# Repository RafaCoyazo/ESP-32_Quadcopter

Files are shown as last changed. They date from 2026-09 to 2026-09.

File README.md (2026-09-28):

# ESP-32_Quadcopter

Purpose:
This repository documents a summer project dedicated to designing and building a custom quadcopter from scratch. At the core of the drone is a custom-designed PCB featuring an ESP32 microcontroller and an onboard accelerometer. While the final build has not yet achieved stable flight, the project served as an intensive, hands-on exploration of embedded C++, custom PCB routing, and writing raw PID control loops for hardware stabilization.

## Current Status & Known Issues

The physical build and custom PCB are complete, and the ESP32 successfully interfaces with the MPU6050 IMU and all four ESCs. However, the drone currently experiences a thrust imbalance where the rear motors do not reach the same RPM as the front motors, preventing a stable takeoff. 

**Troubleshooting to date:**

* Swapped the rear ESCs to rule out faulty hardware; the RPM deficit persisted.
* The isolated problem likely lies within the firmware's motor mixing logic, a bug in the PWM signal generation routed to the rear pins, or an uncompensated center of gravity on the 3D-printed frame.

## Hardware & Design

## Hardware Specifications

| Component | Description |
| :--- | :--- |
| **Microcontroller Evolution** | **V1 & V2:** Arduino (View [Version 1 Details](./Version_1) and [Version 2 Details](./Version_2))
|**Version 3**| **V3 Details of the Hardware:** [Version 3 Details](./Version_3)
  
* **Flight Controller:**
  * **Version 1:** Initial proof-of-concept testing was done using an Arduino and jumper wires.
  *  **Version 2:** Upgraded to a custom double-layer PCB (View the [KiCad Project Files](./Version_3/KiCadV3)) to show proof of concept with Arduino Nano
  * **Version 3:** Redigned custom double-layer PCB (View the [KiCad Project Files](./Version_3/KiCadV3)) to integrate the ESP32 and peripherals, wiring and reduce electrical noise.
 * **Schematic Design for V3**
*(Below: The wiring schematic integrating the ESP32 microcontroller, MPU6050 IMU, and peripheral modules.)*
  
  

**Frame Design & Manufacturing** 
*(Below: The original CAD model showcasing the structural assembly, followed by the final 3D-printed physical frame.)*


rplace with image]

## Software 

* **Language & Codebase Evolution:**
  * **V1 & V2:** Arduino / C++ (View [Version 1 Code](./Version_1) and [Version 2 Code](./Version_2)).
  * **V3:** Embedded C++ (View [Version 3 Code](./Version_3/CodeV3)).
* **Flight Logic:** Custom-written PID control loops to process IMU data and calculate real-time motor compensation.
* **Communication:** I2C protocol for reading sensor telemetry and PWM signal generation for the ESCs.

## Project Media
*(Note to self: Upload a photo of the completed drone and video)*

## Takeoff Dynamics & Motor Imbalance Diagnostics

During takeoff testing, the aircraft experienced a severe pitch imbalance where the rear motors visibly and physically generated significantly lower RPM and thrust compared to the front motors, preventing vertical liftoff.

### Diagnosed Causes & Experimental Troubleshooting:

1. **Power Supply & Input Voltage Verification:**
   * **Action:** Measured the primary voltage supply lines under load to check for power starvation or voltage drops to the rear power distribution traces.
   * **Result:** Confirmed that the power supply unit consistently delivers 12V across all board rails and ESC power feeds. Power delivery was ruled out as the root cause.

2. **ESC Timing, Calibration & Hardware Swaps:**
   * **Hypothesis:** Because four individual ESCs are used rather than an integrated 4-in-1 board, timing drift or throttle calibration offsets could cause rotational speed discrepancies between channels.
   * **Action:** Replaced the rear Electronic Speed Controllers with brand-new units to test for hardware degradation and calibration drift.
   * **Result:** Installing new ESCs slightly increased the RPM of one rear motor, but the total thrust was still insufficient to equalize the outputs. This confirms that while minor ESC variances exist, the main bottleneck is not faulty ESC hardware.

3. **Firmware Pitch Control Loops & Sensor Isolation:**
   * **Action:** To test if the MPU6050 IMU feedback loop was falsely commanding lower duty cycles to the rear channels, firmware was modified to temporarily isolate and disable active pitch compensation.
   * **Result:** Testing is currently ongoing to evaluate raw PWM output signal scaling, timer channel allocations on the ESP32 pins, and pitch PID loop behavior.

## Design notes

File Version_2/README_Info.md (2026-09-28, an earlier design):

# Version 2: Failure Analysis & Root Cause Analysis

## Overview
Version 2 was designed to resolve the wireless link drops and signal instability observed in the initial Version 1 breadboard setup. The objective was to eliminate point-to-point jumper wire noise by routing a custom double-layer PCB in KiCad and upgrading the RF transceivers. However, despite custom PCB fabrication and hardware iteration, persistent communication failures prevented stable flight operations, ultimately deciding to pivot to the ESP32 in Version 3.

## Initial Problem Statement and Hypotheses
During testing on Version 1, the flight controller failed to establish a stable wireless connection between the Arduino Nano and the initial 2.4 GHz NRF24L01+ radio module. 

Primary Hypothesis: High jumper wire impedance, breadboard contact resistance, and causing signal degradation into the SPI bus lines, preventing proper module initialization.
## Experimental Iterations and Diagnostics
To test this hypothesis and systematically isolate the failure, so I made a custom PCB and tested across two transceiver configurations:

1. Custom Double-Layer PCB Fabrication (NRF24L01+ Testing)
Designed and fabricated a custom double-layer flight controller PCB in KiCad to eliminate all long jumper wires and point-to-point breadboard connections. The board integrated socket headers for the LAFVIN Arduino Nano V3.0, dedicated ground copper pours, and direct trace routing to an NRF24L01+ header.

Result: Eliminating the long wires via the custom PCB did not resolve the connection failure, proving that signal path length and breadboard noise were not the primary root cause.

3. Transceiver Module Swap (CC1101 on original PCB Layout)
Using the same custom PCB design, the NRF24L01+ module was replaced with a CC1101 multi-band wireless module equipped with an external SMA antenna to test if switching radio architecture and frequency bands would establish a connection.
Result: The CC1101 module on the custom PCB also failed to achieve reliable communication, meaning there was another cause for this problem.

## Root Cause Breakdown
After these hardware iterations across breadboards and custom PCBs, three core problems were found:

A. Microcontroller Processing and SPI Overhead
The ATmega328P (16 MHz single-core) microcontroller on the Arduino Nano lacked the processing bandwidth to reliably manage low-level SPI transceiver state machines while simultaneously executing high-frequency MPU6050 IMU reads, PID calculations, and ESC PWM updates.

B. SPI Bus Sensitivity and Driver Instability
External SPI radio modules require heavy software polling and strict timing buffers. Power ripple from motor draws or minor bus timing delays caused the SPI driver to hang, freezing communication entirely regardless of whether wires or copper PCB traces were used.

C. Airframe Mechanical Flexibility
The initial 3D-printed airframe lacked structural rigidity, allowing motor vibrations to transfer directly to the flight controller board and IMU sensor, adding mechanical noise into the system.

## Key Lessons and to improve on to Version 3
Rather than continuing to debug an architectural combination (Arduino Nano + External SPI Radio) that repeatedly failed on both breadboards and custom PCBs, the project was restructured for Version 3:

Microcontroller Upgrade: Migrated from the ATmega328P Ardunio to the ESP32 DevKit , providing better clock speed and memory overhead and a built in comunication module.

(ESP-NOW): Scrapped external SPI transceivers entirely in favor of the ESP32's native ESP-NOW protocol. ESP-NOW communicates directly on the Wi-Fi MAC layer, completely removing SPI hardware buses, radio sub-boards, and external driver overhead.

Airframe Redesign: Redesigned the 3D-printed frame in CAD with optimized infill geometry and wall thickness to isolate motor vibrations from the flight controller board.

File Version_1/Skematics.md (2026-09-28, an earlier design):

# Version 1: Schematics & Build Photos


Below is the wiring schematic and early prototype photos for the Version 1 drone build.

## Schematic Diagram


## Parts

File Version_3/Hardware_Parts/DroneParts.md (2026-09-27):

# Drone Hardware: Bill of Materials (BOM)

Below is the complete list of components required for the Version 3 quadcopter build and the custom ground controller, including both off-the-shelf electronics and custom-manufactured parts.

## Custom Manufactured Parts
| Component | Specification / Origin | Quantity | Notes |
| :--- | :--- | :--- | :--- |
| **Flight Controller Board** | Custom Double-Layer PCB | 1 | Routed in KiCad. (View [KiCad Project Files](../KiCadV3)) |
| **Quadcopter Frame** | Custom FDM 3D Print | 1 | Modeled in SolidWorks and Fusion 360. Includes arms, top plate, and undercarriage. (View [CAD Files](../CadFilesV3)) |
| **Controller Enclosure** | Custom FDM 3D Print | 1 | Houses the ESP32 transmitter board, dual joysticks, and wiring. |

## Off-The-Shelf Electronics
| Component | Specification / Model | Quantity | Notes |
| :--- | :--- | :--- | :--- |
| **Microcontroller** | ESP-WROOM-32 ESP32 Development Board | 2 | 2.4GHz Dual-Core WiFi/Bluetooth. (1 for the flight controller, 1 for the remote controller) |
| **Controller Joysticks** | KY-023 Dual-axis XY Joystick Module | 2 | PS2-style analog joysticks for reading pilot input (Throttle/Yaw, Pitch/Roll) |
| **Motors** | A2212 1000KV Brushless Outrunner | 4 | Configured for an 880g thrust profile on a 3S battery |
| **Propellers** | 1045 CW & CCW Props | 4 | 2 Clockwise, 2 Counter-Clockwise |
| **ESCs** | 40A OPTO 2-6S Brushless ESC | 4 | Handles motor current distribution without an integrated BEC |
| **IMU / Sensor** | GY-521 MPU6050 | 1 | 6-Axis Accelerometer and Gyroscope communicating via I2C |
| **Power Distribution** | Acxico 3-4S PDB with XT60 | 1 | Steps down battery voltage to provide clean 5V/12V logic power |
| **Battery** | 11.1V 3S 2200mAh 50C LiPo | 1 | High-discharge power source for flight |
| **Connectors** | XT60 Pigtails (14AWG Wire) | As needed | Soldered for high-current battery mating and power routing |

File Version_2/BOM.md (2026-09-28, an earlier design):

# Version 2: Hardware Bill of Materials (BOM)

Below is the list of components for the Version 2 build. This iteration marks the transition away from off-the-shelf prototyping boards to the first custom-designed PCB and the initial attempt at a 3D-printed airframe.

## Custom Manufactured Parts
| Component | Specification / Origin | Quantity | Notes |
| :--- | :--- | :--- | :--- |
| **Flight Controller Board** | Custom Double-Layer PCB | 1 | Early revision routed in KiCad to replace the point-to-point soldered perfboards. |
| **Quadcopter Frame** | Custom FDM 3D Print | 1 | The initial, highly experimental airframe iteration. (Replaced in Version 3 due to structural/flight issues). |

## Off-The-Shelf Electronics
| Component | Specification / Model | Quantity | Notes |
| :--- | :--- | :--- | :--- |
| **Microcontroller** | LAFVIN Nano V3.0 (ATmega328P) | 2 | Retained from Version 1 for both flight and ground control logic. |
| **Wireless Module** | CC1101 Multi-Band Wireless Module | 2 | Swapped in to replace the NRF24L01+. Includes an SMA antenna for improved range and stability. |
| **Motors** | A2212 1000KV Brushless Motors 13T | 4 | High-torque outrunner motors equipped with pre-soldered 3.5mm banana plugs. |
| **ESCs** | 30A OPTO 2-6S Brushless ESC | 4 | Electronic speed controllers for power distribution to the motors. |

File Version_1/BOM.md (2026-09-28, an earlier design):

# Version 1: Hardware Bill of Materials (BOM)

Below is the list of early components used in Version 1 of the quadcopter and ground station, prior to the migration to custom PCBs and ESP32 microcontrollers.

| Component | Specification / Model | Quantity | Notes |
| :--- | :--- | :--- | :--- |
| **Microcontroller** | LAFVIN Nano V3.0 (ATmega328P) | 2 | Driven by the CH340 chip. Used for the original flight controller and remote logic.[cite: 12] |
| **Wireless Module** | HiLetgo NRF24L01+ 2.4G Transceiver | 2 | Handled the RF communication link between the remote and the aircraft.[cite: 13] |
| **Prototyping Board** | ElectroCookie Mini PCB Prototype Board | As needed | Used to solder the Nano, NRF24L01+, and wiring point-to-point before custom PCBs were designed.[cite: 16] |
| **Motors** | A2212 1000KV Brushless Motors 13T | 4 | High-torque outrunner motors equipped with pre-soldered 3.5mm banana plugs.[cite: 15] |
| **ESCs** | 30A OPTO 2-6S Brushless ESC | 4 | Electronic speed controllers for power distribution to the motors.[cite: 14] |

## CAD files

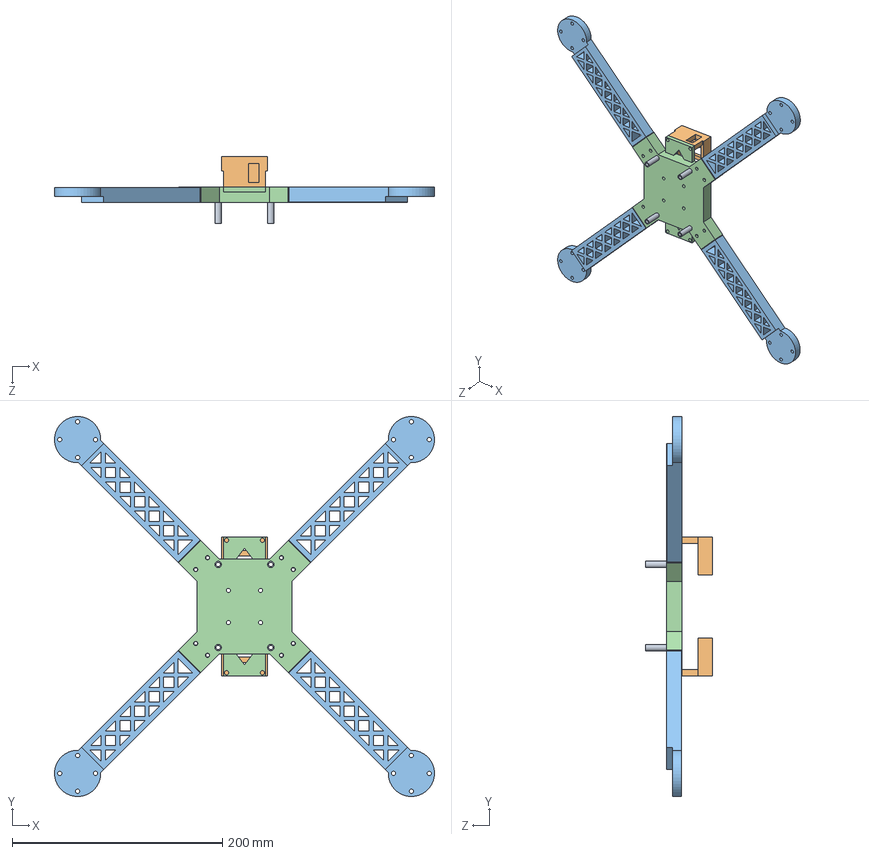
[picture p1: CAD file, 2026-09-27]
Version_3/CadFilesV3/DroneV3Assem.SLDASM
361.2 x 361.2 x 64.0 mm
DroneBaseV3
DroneArmV3.2 x 4
BateryHolderV3.2Left x 2
Support x 4

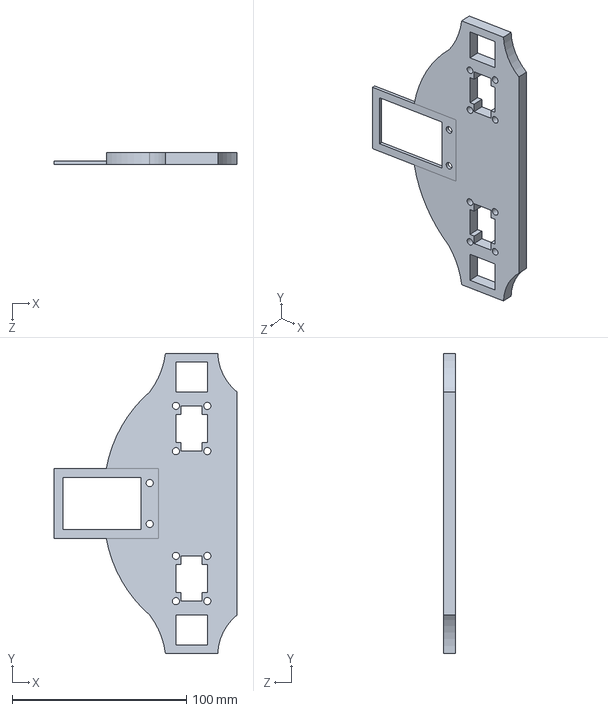
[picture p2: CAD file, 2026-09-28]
Version_3/CadFilesV3/ControllerV2.SLDPRT
104.8 x 172.0 x 7.00 mm

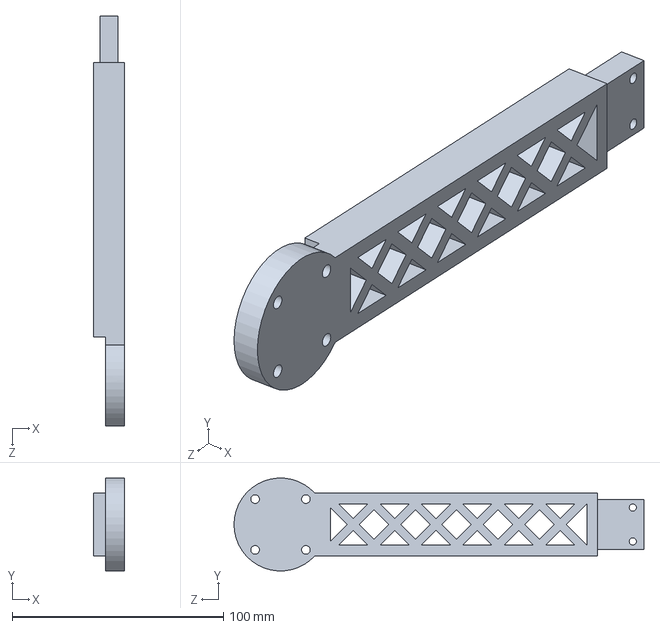
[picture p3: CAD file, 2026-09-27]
Version_3/CadFilesV3/DroneArmV3.2.SLDPRT
14.6 x 44.0 x 194.0 mm

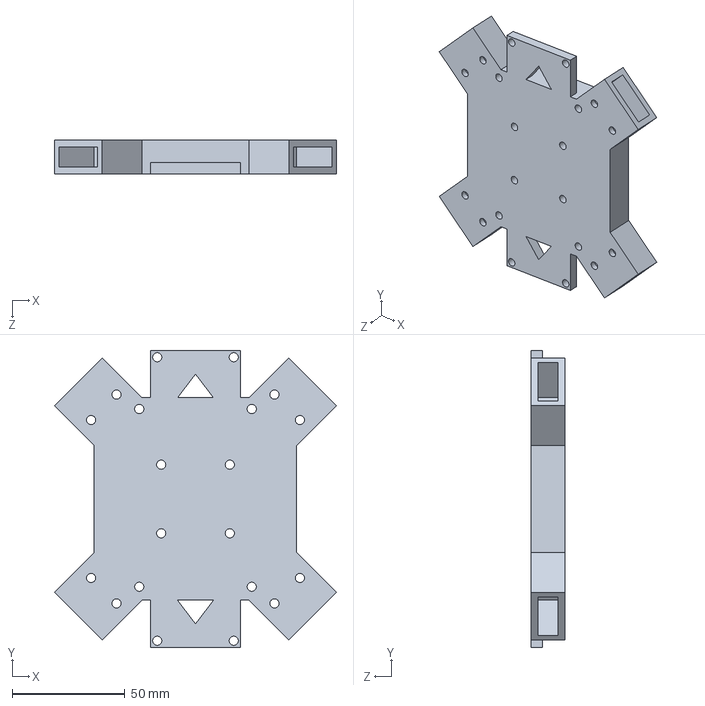
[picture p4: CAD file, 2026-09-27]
Version_3/CadFilesV3/DroneBaseV3.SLDPRT
125.4 x 132.0 x 15.0 mm

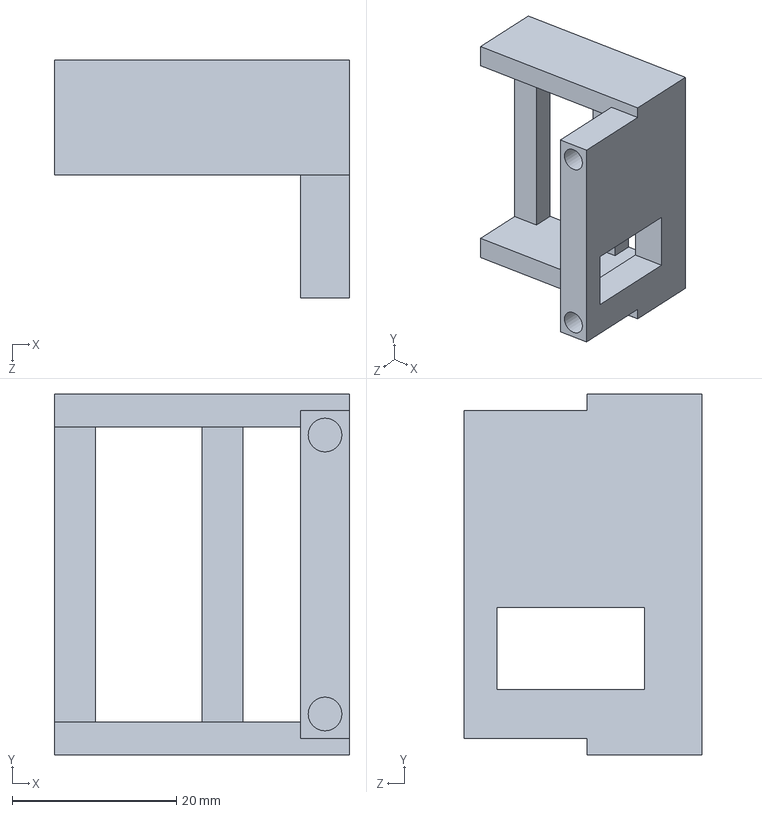
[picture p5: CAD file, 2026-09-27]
Version_3/CadFilesV3/BateryHolderV3.2Left.SLDPRT
36.0 x 44.0 x 29.0 mm

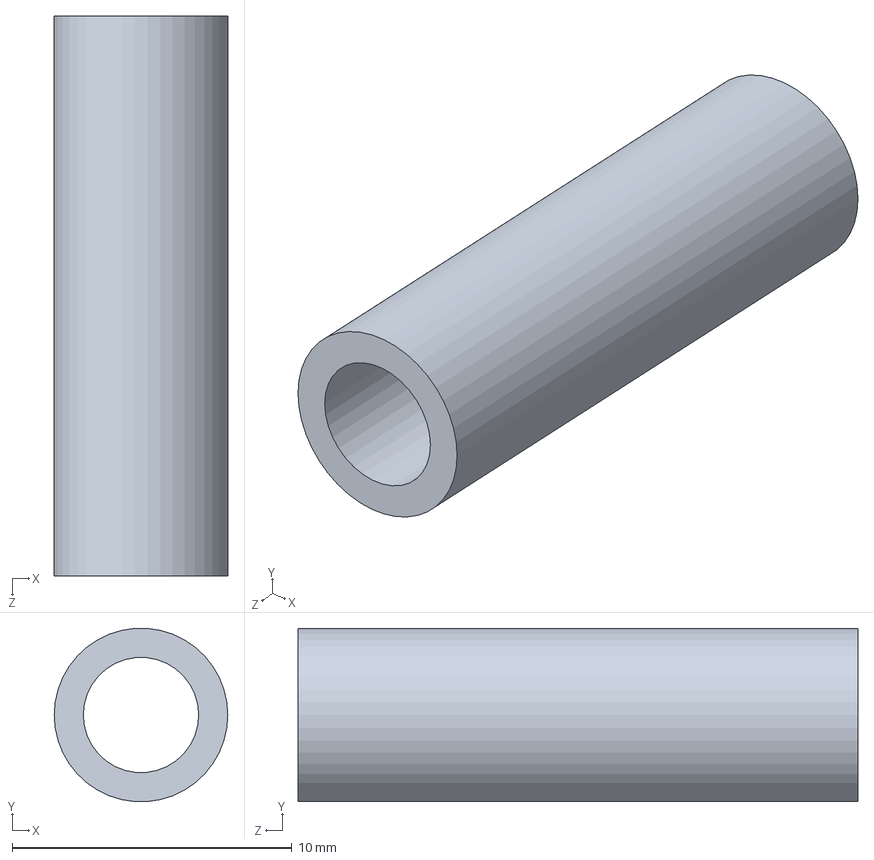
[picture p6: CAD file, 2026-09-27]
Version_3/CadFilesV3/Support.SLDPRT
6.20 x 6.18 x 20.0 mm

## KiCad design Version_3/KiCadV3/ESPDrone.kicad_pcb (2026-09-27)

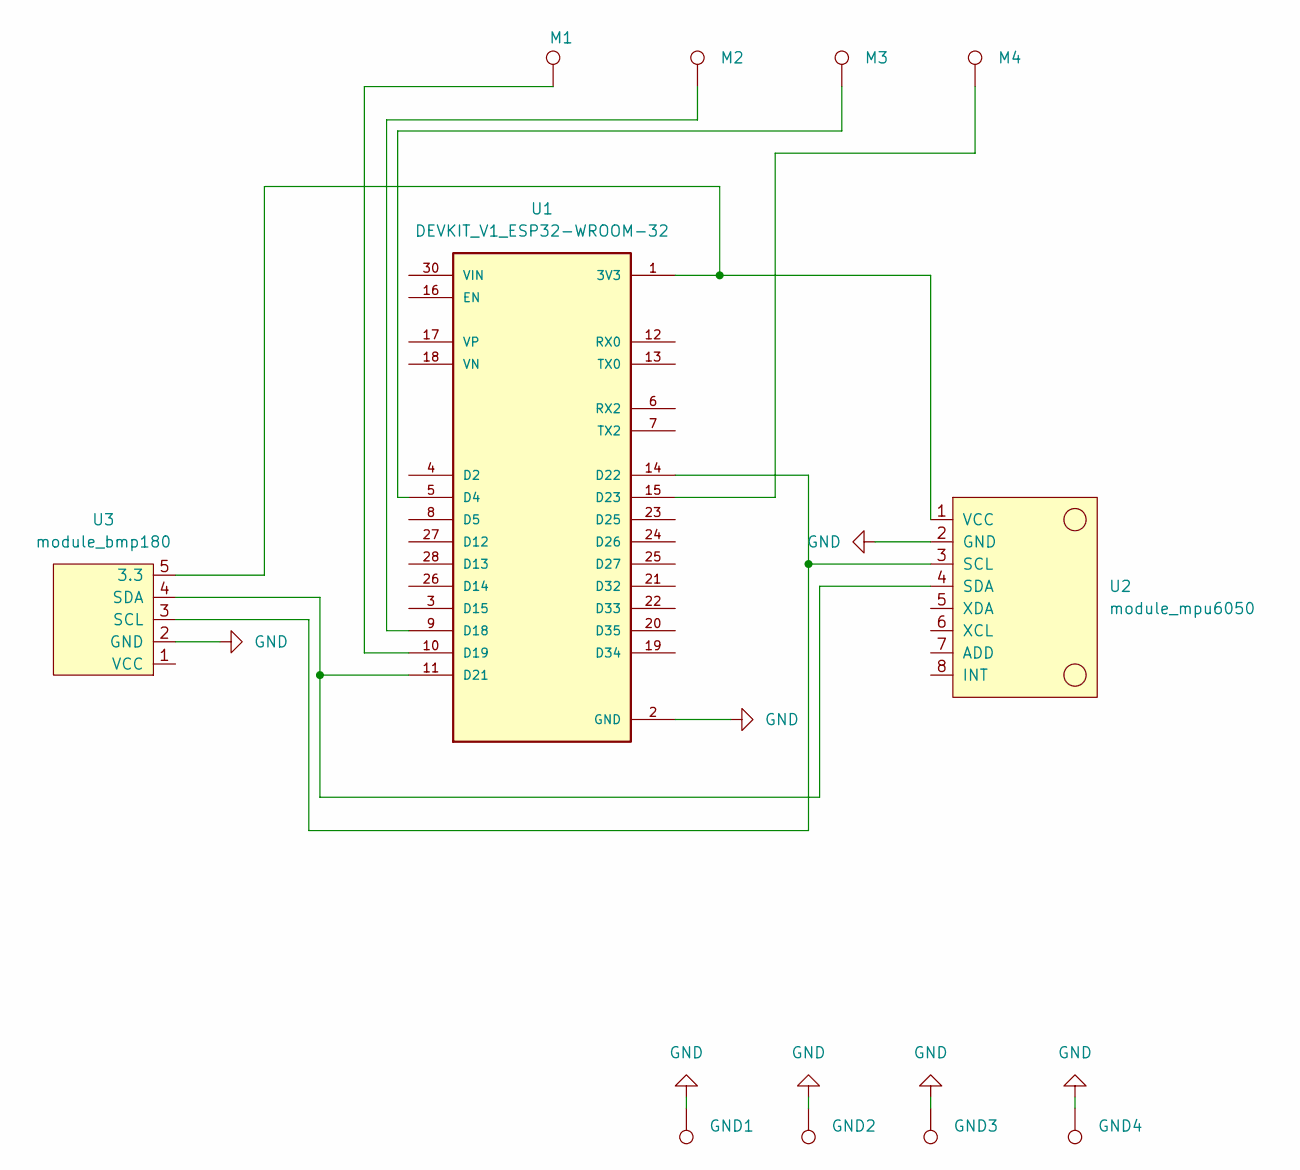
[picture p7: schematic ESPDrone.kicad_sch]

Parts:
GND1, GND2, GND3, GND4: TestPoint; TestPoint_THTPad_2.0x2.0mm_Drill1.0mm
M1: M1; TestPoint_THTPad_2.0x2.0mm_Drill1.0mm
M2, M3, M4: TestPoint; TestPoint_THTPad_2.0x2.0mm_Drill1.0mm
U1: DEVKIT_V1_ESP32-WROOM-32; MODULE_DEVKIT_V1_ESP32-WROOM-32
U2: module_mpu6050
U3: module_bmp180

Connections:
GND: GND1.1 (1_1), GND2.1 (1_1), GND3.1 (1_1), GND4.1 (1_1), U1.2 (GND), U1.29 (GND), U2.2 (GND), U3.2 (GND)
unnamed: U1.1 (3V3), U2.1 (VCC), U3.5 (3.3)
unnamed: M3.1 (1_1), U1.5 (D4)
unnamed: M2.1 (1_1), U1.9 (D18)
unnamed: M1.1 (1_1), U1.10 (D19)
unnamed: U1.11 (D21), U2.4 (SDA), U3.4 (SDA)
unnamed: U1.14 (D22), U2.3 (SCL), U3.3 (SCL)
unnamed: M4.1 (1_1), U1.15 (D23)

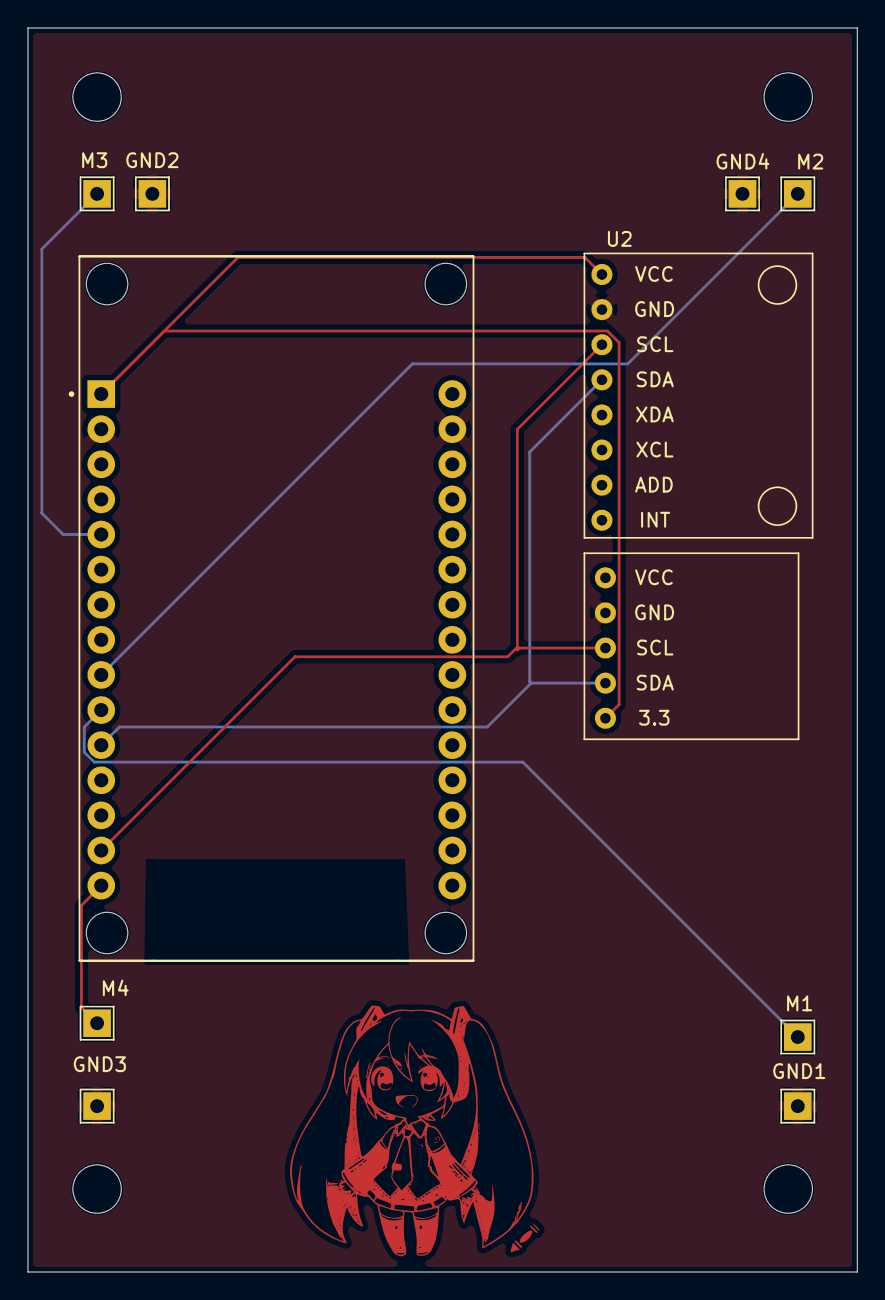
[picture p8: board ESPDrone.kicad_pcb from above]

Board: 4 copper layers, 60.0 x 90.0 mm, 11 parts (0 on the bottom side), 8 nets.

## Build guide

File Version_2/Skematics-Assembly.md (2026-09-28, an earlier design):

# Version 2: Schematics & Assembly

Below are the wiring diagrams and CAD Assembly for the Version 2 drone build. This iteration highlights the transition to a custom-routed PCB and the first prototype of a 3D-printed airframe.

## Schematics



## Custom PCB
unnamed
Add 1 more photo

## CAD Assembly


## Drone Build




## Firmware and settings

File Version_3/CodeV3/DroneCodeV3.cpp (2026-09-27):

#include <esp_now.h>
#include <WiFi.h>
#include <Adafruit_MPU6050.h>
#include <Adafruit_Sensor.h>
#include <Wire.h>
#include <ESP32Servo.h>

// Instance of MPU and Electronic Speed Converter (esc)
Adafruit_MPU6050 mpu;
Servo ESC_TopRight, ESC_TopLeft, ESC_BotRight, ESC_BotLeft;

//------------------------------------------------------------------------------------------------------------------------------------------------

// Calibrating offsets
float Pich_offset = 0.0;
float Roll_offset = 0.0;

// Pin and Pluse Ranges for the ESC
const int TopRight = 18;      // SignalWires GPIO Pins
const int TopLeft = 4;
const int BotRight = 19;
const int BotLeft = 23;

// Max and Min pulses for the ESCs
const int Min_pulse = 1000;  // 0% throttle (1000us)
const int Max_pulse = 2000;  // 100% throttle (2000us)

// Data Structure for Rreceiving and Transceiving data
typedef struct struct_message {
   int throttle;  // 0 to 100 (0 = 0% throttle, 1000 = 100% throttle)
   int pitch;     // -1000 to +1000 (-1000 = full back , +1000 = full foward)
   int roll;      // -1000 to +1000 (-1000 = full left , +1000 = full right)
} struct_message;

typedef struct telemetry_message {
   int motorTR;
   int motorTL;
   int motorBR;
   int motorBL;
} telemetry_message;

// Global variables for sharing data between interuptions and callback loop
unsigned long LastTelemetryTime = 0;
const int TelemetryInterval = 50; // Send telemetry every 50ms

volatile bool NewDataAvailable = false;   
struct_message IncomingData;       // Recieving Data
telemetry_message OutgoingData;    // Telmetry Data

// Fail Safe Timers
unsigned long LastPacketTime = 0;
const unsigned long STAGE1_TIMEOUT = 300;  // 300ms  Controlled level descent
const unsigned long STAGE2_TIMEOUT = 2000; // 2s   Hard disarm

//------------------------------------------------------------------------------------------------------------------------------------------------

// PID Gains
float Kp_pitch = 1.3, Ki_pitch = 0.02, Kd_pitch = 18.0;
float Kp_roll  = 1.3, Ki_roll  = 0.02, Kd_roll  = 18.0;

// PID State Variables
float error_pitch, prev_error_pitch, i_pitch, pid_pitch;
float error_roll,  prev_error_roll,  i_roll,  pid_roll;

unsigned long PrevTime = 0;

//------------------------------------------------------------------------------------------------------------------------------------------------

//  Callback: When Data is Sent
void OnDataSent(const wifi_tx_info_t *info, esp_now_send_status_t status) {
  // Reserved for outgoing telemetry status
}

// Callback: When Data Recvieved
void OnDataRecv(const esp_now_recv_info_t *recv_info, const uint8_t *data, int len) {
  memcpy(&IncomingData, data, sizeof(IncomingData));
  NewDataAvailable = true;
  LastPacketTime = millis(); // Refresh connection timer
}

void StopAllMotors() {
  ESC_TopRight.writeMicroseconds(Min_pulse);
  ESC_TopLeft.writeMicroseconds(Min_pulse);
  ESC_BotRight.writeMicroseconds(Min_pulse);
  ESC_BotLeft.writeMicroseconds(Min_pulse);

  // Reset I-terms when disarmed to prevent wind-up
  i_pitch = 0;
  i_roll = 0;
}

//------------------------------------------------------------------------------------------------------------------------------------------------

void setup() {
  Serial.begin(115200);

  Wire.begin(21, 22);

  if (!mpu.begin()) {
    Serial.println("Error: MPU6050 not detected on drone!");
    
  } else {
      Serial.println("Drone IMU (MPU6050) Ready!");

      mpu.setAccelerometerRange(MPU6050_RANGE_8_G);
      mpu.setGyroRange(MPU6050_RANGE_500_DEG);
      mpu.setFilterBandwidth(MPU6050_BAND_21_HZ);

      Serial.println("Calibrating MPU6050... DO NOT MOVE DRONE!");
      delay(2000); // 2-second delay so you can take your hands off the drone

      int Num_samples = 200;
      for (int i = 0; i < Num_samples; i++) {
        sensors_event_t a, g, temp;
        mpu.getEvent(&a, &g, &temp);
  
        Pich_offset += atan2(-a.acceleration.y, sqrt(a.acceleration.x * a.acceleration.x + a.acceleration.z * a.acceleration.z)) * 57.3;
        Roll_offset += atan2(-a.acceleration.x, a.acceleration.z) * 57.3;
        delay(10);
    }

    Pich_offset /= Num_samples;
    Roll_offset /= Num_samples;

    Serial.print("Offsets -> Pitch: "); Serial.print(Pich_offset);
    Serial.print(" | Roll: "); Serial.println(Roll_offset);
    Serial.println("Calibration complete!");
  }
  
  // Timer for ESC Signals
  ESP32PWM::allocateTimer(0);
  ESP32PWM::allocateTimer(1);

  // Attaches the pins and Max and Min pulses for ESC
  ESC_TopRight.attach(TopRight, Min_pulse, Max_pulse);
  ESC_TopLeft.attach(TopLeft, Min_pulse, Max_pulse);
  ESC_BotRight.attach(BotRight, Min_pulse, Max_pulse);
  ESC_BotLeft.attach(BotLeft, Min_pulse, Max_pulse);

  // Arming ESCs, Motors
  Serial.println("Arming ESCs...");
  StopAllMotors();
  delay(3000);
  Serial.println("ESCs Armed.");

  //Setting Up ESP Now
  WiFi.mode(WIFI_STA);
  if (esp_now_init() != ESP_OK) {
    Serial.println("Error initializing ESP-NOW");
    return;
  }

  // Register send and receive callbacks
  esp_now_register_send_cb(OnDataSent);
  esp_now_register_recv_cb(OnDataRecv);

  // Register Controller as peer
  memcpy(peerInfo.peer_addr, controllerAddress, 6);
  peerInfo.channel = 0;  
  peerInfo.encrypt = false;
  
  if (esp_now_add_peer(&peerInfo) != ESP_OK) {
    Serial.println("Failed to add peer");
    return;
  }

  Serial.println("Drone Receiver Ready! Waiting for joystick signals...\n");
  
  LastPacketTime = millis(); // Initialize failsafe timer
  PrevTime = micros();
}

//------------------------------------------------------------------------------------------------------------------------------------------------

void loop() {
  // Calculate delta time (dt) in seconds
  unsigned long CurrentTime = micros();
  float dt = (CurrentTime - PrevTime) / 1000000.0;

  // Rest clock
  PrevTime = CurrentTime;
  
  // Read MPU6050
  sensors_event_t a, g, temp;
  mpu.getEvent(&a, &g, &temp);

  // Raw Pitch && Roll
  float RawPitch = atan2(-a.acceleration.y, sqrt(a.acceleration.x * a.acceleration.x + a.acceleration.z * a.acceleration.z)) * 57.3;
  float RawRoll  = atan2(-a.acceleration.x, a.acceleration.z) * 57.3;
 
  // Apply calibration offsets
  float DronePitch = RawPitch - Pich_offset;
  float DroneRoll  = RawRoll  - Roll_offset;

  // Flight variables declared before evaluation
  float TargetPitch = 0.0;  // it is 0 bc of prev Testing
  float TargetRoll  = 0.0;
  int BaseThrottle  = Min_pulse;

  unsigned long timeSinceLastPacket = millis() - LastPacketTime;

  // Using the Data \\ -------------------------------------------------------

  // Failsafe 
  if (TimeSinceLastPacket > STAGE2_TIMEOUT) {
    
    // --- STAGE 2: Hard Cut (Safety Disarm) ---
    
    StopAllMotors();
    
    return; // Exit loop early to prevent motor updates
    
  } 
  else if (TimeSinceLastPacket > STAGE1_TIMEOUT) {
    
 StopAllMotors(); // Is a hard cut off bc I hurt myslef :(
    
 return; // Exit loop early to prevent motor updates
    
  } 
  else {
    // Joystick inputs (-1000 to +1000) to target tilt angles (-20° to +20°)
    TargetPitch  = map(IncomingData.pitch, -1000, 1000, -20, 20);
    TargetRoll   = map(IncomingData.roll,  -1000, 1000, -20, 20);
    BaseThrottle = map(IncomingData.throttle, 0, 1000, Min_pulse, Max_pulse);
    
    if (IncomingData.throttle <= 10) {
    
      // Safety: If throttle is at absolute minimum (disarmed state), turn off motors completely
    StopAllMotors();

    return;
    }
  }

// Calculate Errors
error_pitch = TargetPitch - DronePitch;
error_roll  = TargetRoll  - DroneRoll;

//  P (Proportional) 
float p_pitch = 0;  //Kp_pitch * error_pitch; Zeroed for testing purposes
float p_roll  = 0;  //Kp_roll  * error_roll;  

// --- D (Derivative) ---
float d_pitch = -Kd_pitch * (g.gyro.x * 57.3);
float d_roll  = -Kd_roll  * (g.gyro.y * 57.3);

// --- I (Integral) & Total PID ---
// Only calculate I-term when throttle is active to prevent ground wind-up
if (BaseThrottle > 1050) {
    i_pitch += Ki_pitch * error_pitch * dt;
    i_roll  += Ki_roll  * error_roll  * dt;
    i_pitch  = constrain(i_pitch, -40, 40); 
    i_roll   = constrain(i_roll,  -40, 40);

    pid_pitch = p_pitch + i_pitch + d_pitch;
    pid_roll  = p_roll  + i_roll  + d_roll;
} else {
    // Reset I-terms and PID outputs to 0 when idle on the ground
    i_pitch = 0;
    i_roll = 0;
    pid_pitch = 0;
    pid_roll = 0;
  }
  
  // Constrain total PID output to a safe, flight-ready pulse limit (+/- 40us)
  pid_pitch = constrain(pid_pitch, -40, 40);
  pid_roll  = constrain(pid_roll, -40, 40);

  // Quadcopter X-Frame Motor Mixing Math
  // TopRight (Front-Right): -pitch, -roll
  // TopLeft  (Front-Left):  -pitch, +roll
  // BotRight (Rear-Right):  +pitch, -roll
  // BotLeft  (Rear-Left):   +pitch, +roll

  // Apply PID offsets to Motor Matrix
  int PulseTR = BaseThrottle - pid_pitch - pid_roll;
  int PulseTL = BaseThrottle - pid_pitch + pid_roll;
  int PulseBR = BaseThrottle + pid_pitch - pid_roll;
  int PulseBL = BaseThrottle + pid_pitch + pid_roll;

  //  DOing mirco pulses
  PulseTR = constrain(PulseTR, Min_pulse, Max_pulse);
  PulseTL = constrain(PulseTL, Min_pulse, Max_pulse);
  PulseBR = constrain(PulseBR, Min_pulse, Max_pulse);
  PulseBL = constrain(PulseBL, Min_pulse, Max_pulse);

  // Sending the pulses
  ESC_TopRight.writeMicroseconds(PulseTR);
  ESC_TopLeft.writeMicroseconds(PulseTL);
  ESC_BotRight.writeMicroseconds(PulseBR);
  ESC_BotLeft.writeMicroseconds(PulseBL);

  // Limiting the amount of into gets sent to not overworks computer
  if (millis() - LastTelemetryTime > TelemetryInterval) {
    // Pack the current pulses into the struct
    outgoingData.motorTR = PulseTR;
    outgoingData.motorTL = PulseTL;
    outgoingData.motorBR = PulseBR;
    outgoingData.motorBL = PulseBL;

    // Send it back to the controller's MAC address
    esp_now_send(controllerAddress, (uint8_t *) &outgoingData, sizeof(outgoingData));
      
    // Reset the timer
    LastTelemetryTime = millis();
    }
    
  // Serial Debug Print
  Serial.print("Throt: "); Serial.print(IncomingData.throttle);
  Serial.print(" | Pitch: "); Serial.print(IncomingData.pitch);
  Serial.print(" | Roll: "); Serial.println(IncomingData.roll);

  // Delay to prevent overload
  delay(10);
  
}

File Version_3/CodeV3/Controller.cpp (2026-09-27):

#include <esp_now.h>
#include <WiFi.h>

// Joystick Pins
const int PIN_THROTTLE = 34; 
const int PIN_PITCH    = 33;
const int PIN_ROLL     = 32;

// Mac Address
uint8_t droneAddress[] = {0x20, 0x9B, 0xA9, 0x98, 0x0B, 0x38};
esp_now_peer_info_t peerInfo;

// Data Structure for recieving and telemetry
typedef struct struct_message {
   int throttle;  // 0 to 1000
   int pitch;     // -1000 to +1000
   int roll;      // -1000 to +1000
} struct_message;

typedef struct telemetry_message {
   int motorTR;
   int motorTL;
   int motorBR;
   int motorBL;
} telemetry_message;

struct_message outgoingData;
telemetry_message incomingTelemetry;

// Global variable to hold the throttle value
float CurrentThrottle = 0; 

// Call backs
// Callback when data is sent
void OnDataSent(const wifi_tx_info_t *info, esp_now_send_status_t status) {
  //Extra code in case needed to do something when data is sent
}

// Callback when telemetry is received
void OnDataRecv(const esp_now_recv_info_t *recv_info, const uint8_t *data, int len) {
  
  // Check if we received the correct telemetry size
  if (len == sizeof(telemetry_message)) {
    memcpy(&incomingTelemetry, data, sizeof(incomingTelemetry));
    
    // Print the motor pulses to the Serial Monitor
    Serial.print("Telemetry | TR: "); Serial.print(incomingTelemetry.motorTR);
    Serial.print(" | TL: "); Serial.print(incomingTelemetry.motorTL);
    Serial.print(" | BR: "); Serial.print(incomingTelemetry.motorBR);
    Serial.print(" | BL: "); Serial.println(incomingTelemetry.motorBL);
  }
}

// Set up ----------------------------------------------------------------------------------------------------------------------------------------
void setup() {
  Serial.begin(115200);

  WiFi.mode(WIFI_STA);

  if (esp_now_init() != ESP_OK) {
    Serial.println("Error initializing ESP-NOW");
    return;
  }

  // Register callbacks
  esp_now_register_send_cb(OnDataSent);
  esp_now_register_recv_cb(OnDataRecv);

  // Register Drone as peer
  memcpy(peerInfo.peer_addr, droneAddress, 6);
  peerInfo.channel = 0;  
  peerInfo.encrypt = false;
  
  if (esp_now_add_peer(&peerInfo) != ESP_OK) {
    Serial.println("Failed to add peer");
    return;
  }

  Serial.println("Controller Ready! Reading joysticks...");
}

// Main Loop -------------------------------------------------------------------------------------------------------------------------------------------

void loop() {
  // Read Joysticks
  int RawThrottle = analogRead(PIN_THROTTLE);
  int RawPitch    = analogRead(PIN_PITCH);
  int RawRoll     = analogRead(PIN_ROLL);

  // Throttle Logic
  // The centered joystick reads around 2048 so aprox change would be blow 1800 or above 2200
  if (RawThrottle > 2200) {
    CurrentThrottle += 10; // Pushing up increases throttle
  } else if (RawThrottle < 1800) {
    CurrentThrottle -= 10; // Pulling down decreases throttle
  }

  // Keep the counter between 0 and 1000
  CurrentThrottle = constrain(CurrentThrottle, 0, 1000);
  outgoingData.throttle = (int)CurrentThrottle;

  // Pitch and Roll remain mapped directly to the stick position
  outgoingData.pitch    = map(RawPitch, 0, 4095, -1000, 1000);
  outgoingData.roll     = map(RawRoll, 0, 4095, -1000, 1000);

  // Add a small deadband so the drone doesn't drift when sticks are centered
  if (abs(outgoingData.pitch) < 500) outgoingData.pitch = 0;
  if (abs(outgoingData.roll) < 500)  outgoingData.roll = 0;

  //Sending to the drone
  esp_now_send(droneAddress, (uint8_t *) &outgoingData, sizeof(outgoingData));

  // Run at ~20Hz (every 50ms) so we don't flood the Wi-Fi channel
  delay(50);
}
